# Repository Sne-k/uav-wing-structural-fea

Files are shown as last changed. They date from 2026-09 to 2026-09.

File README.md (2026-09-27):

# UAV Wing: Structural FEA (Fusion 360 + Ansys)

Design and finite-element analysis of a tapered UAV wing with skin, two spars and
ten ribs. This was a 6th-semester FEA project in B.Tech Aeronautical Engineering.

* **CAD:** Autodesk Fusion 360. The NACA 2412 airfoil is imported with a Python
  script, lofted, and given spars and ribs.
* **FEA:** Ansys Workbench 2026 R1 Student. Static structural, modal (6 modes),
  stress-life fatigue, and aluminium vs CFRP.
* **Audit and re-analysis:** the saved Ansys model was checked against its own
  solver files and against hand calculations. It was then re-solved with a small,
  benchmark-verified shell FE code with a corrected set-up. The analyses that
  were missing were also added: a derived design load, mesh convergence, skin
  sizing with buckling, a real composite layup with Tsai-Wu, fatigue and flutter.

<p align="center">
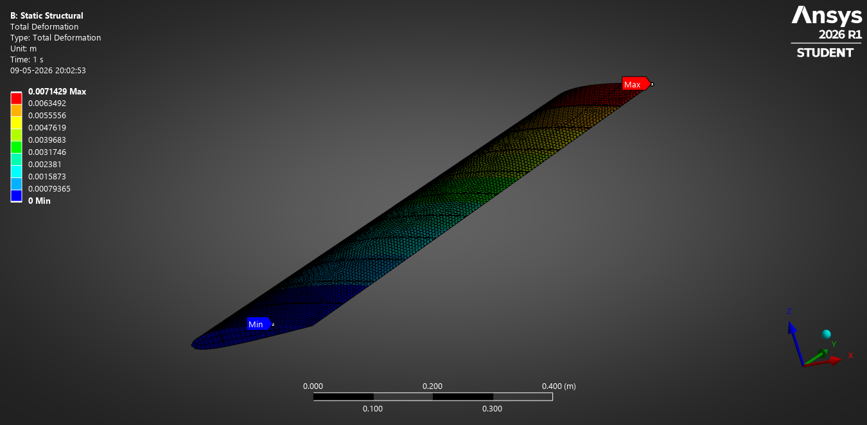
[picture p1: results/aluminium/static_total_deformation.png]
Ansys total deformation
  
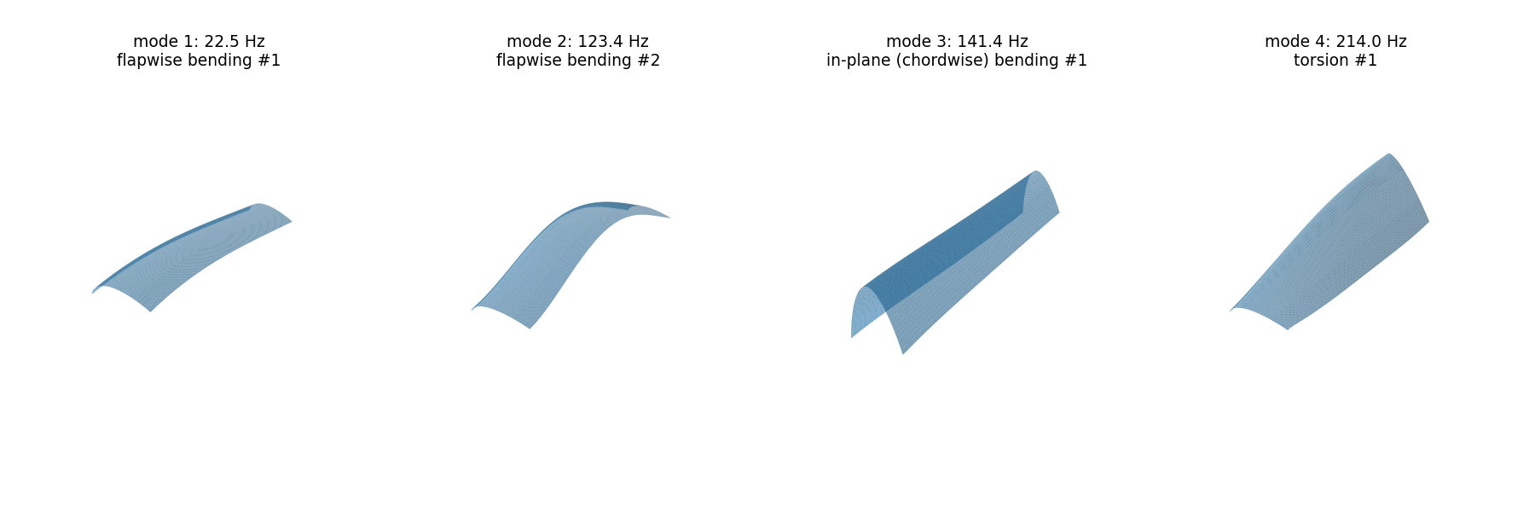
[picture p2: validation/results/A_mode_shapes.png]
Mode shapes of the corrected model
  
</p>

## The wing

| Item | Value |
|---|---|
| Airfoil | NACA 2412 |
| Semi-span | 1.2 m |
| Chord | 0.25 m at the root to 0.20 m at the tip (taper 0.8), straight leading edge, no sweep or twist |
| Front spar | straight, at 25 % of the root chord (x = 62.5 mm), 20 × 5 mm |
| Rear spar | tapered, on the 70 % chord line, 17 × 5 mm at the root |
| Ribs | 10, about 2 mm thick, 109 mm pitch |
| Materials | aluminium alloy (E 70 GPa, ρ 2700 kg/m³); "CFRP" (E 70 GPa, ρ 1600 kg/m³) |

## Workflow

```mermaid
flowchart LR
  A[Literature review<br/>5 papers] --> B[NACA 2412 .dat<br/>Fusion 360 script]
  B --> C[Loft, spars, ribs<br/>STEP export]
  C --> D[Ansys Workbench<br/>shell + solid mesh]
  D --> E[Static / modal /<br/>fatigue / CFRP]
  E --> F[Audit of solver decks<br/>and results]
  F --> G[Verified re-analysis<br/>validation/]
```

## Results of the original Ansys model

| Analysis | Aluminium | "CFRP" |
|---|---|---|
| Mass (semi-span) | 12.42 kg | 7.36 kg |
| Max total deformation | 7.14 mm | 7.14 mm |
| Max von Mises stress | 154.9 MPa | 157.9 MPa |
| Natural frequencies, modes 1–6 | 13.9, 23.9, 37.0, 63.9, 68.1, 87.7 Hz | 18.1, 31.0, 47.8, 83.0, 88.2, 113.9 Hz |
| Fatigue (zero-based, Goodman) | min. life 3.33 × 10⁶ cycles | – |

Screenshots are in [`results/`](results); the model is in [`ansys/`](ansys).

## Verification: what the numbers really say

The same wing solved four ways, all with the same 800 Pa load:

| | Your Ansys deck, as saved | Your Ansys deck, root clamped | Shell FE re-analysis, clamped (mesh-converged) | Beam theory, clamped |
|---|---|---|---|---|
| Tip deflection | 7.14 mm | **2.70 mm** | **2.70 mm** | 2.86 mm |
| Skin stress at the root | peak 154.9 MPa (at the spar root) | **10.6 MPa** | **10.7 MPa** | 10.2 MPa |
| 1st bending frequency | 13.9 Hz | **22.8 Hz** | **22.5 Hz** | 22.5 Hz |
| 1st in-plane bending | 23.9 Hz | **141 Hz** | **141 Hz** | – |
| 1st torsion | not found | **221 Hz** | **214 Hz** | – |

Re-solving the saved deck in Ansys MAPDL reproduces 7.14 mm and 154.9 MPa
exactly. Clamping the root **in that same deck** gives 2.70 mm, the same as
the independent shell model
([validation/ansys_rerun](validation/ansys_rerun/README.md)).
The audit
([docs/model_audit.md](docs/model_audit.md)) traces the difference to the set-up,
not to the software:

1. **Support.** The Fixed Support is on a separate root-cap surface that touches
   only the two spar end faces (8 and 13 contact nodes); the skin's root edge is
   free. The 154.9 MPa peak sits on that contact patch at the rear-spar root
   (22 MPa just 5 cm away). The soft joint also explains the extra deflection and
   the low frequencies.
2. **Load.** The 800 Pa was applied "by components" to the whole skin, so the
   lower surface is pushed up too: 434.6 N per semi-span, twice the intended
   load and about 17 g for a 5 kg UAV.
3. **"CFRP".** Modelled as isotropic with the same modulus as aluminium, so only
   the density changes. Deflection and stress are identical, and every frequency
   rises by exactly √(2700/1600) = 1.299.
4. **Mode 2** is in-plane (fore-aft) bending. **Modes 3–5** are local
   vibrations: modes 3 and 5 at the wing tip, and mode 4 on the front spar
   between ribs 2 and 3 (the spars are joined to the skin only by contact). No
   torsion mode is found. The fatigue life is computed at the same contact
   hotspot.

## Re-analysis and the gaps it fills ([validation/](validation/README.md))

* **Verified solver.** The shell element matches closed-form and published
  results within 1 % for plate bending, vibration, in-plane bending, plate
  buckling and the Scordelis-Lo roof. Closed-box torsion is within 3.3 %, as
  expected, because the clamped end restrains warping.
* **Confirmed in Ansys.** Your own decks, re-solved in Ansys MAPDL, reproduce
  the saved results exactly. With the root clamped they give 2.70 mm,
  22.8 Hz and 221 Hz torsion. With the design load, they give 0.82 mm and
  3.5 MPa in the skin
  ([validation/ansys_rerun](validation/ansys_rerun/README.md)). A corrected
  copy of the Workbench project, solved the same way, gives new screenshots
  ([results/corrected](results/corrected/README.md)).
* **Design load case.** 5 kg MTOW, limit load factor 4, safety factor 1.5.
  Spanwise lift comes from lifting-line theory and is applied to the upper skin
  with the centre of pressure at 25 % chord.
* **Sizing with buckling.** Under the design load the original 8 mm skin has a
  reserve factor of about 90 on ultimate strength. A **0.5 mm aluminium skin**
  passes strength (reserve factor 10 on yield at limit load, 7.7 on ultimate
  strength) and skin buckling (1.4 × ultimate) at **1.08 kg per semi-span
  instead of 12.8 kg**.
  A 0.4 mm skin buckles below ultimate load, so **buckling, not strength, sizes
  the skin**.
* **Real composite.** T300/5208 laminates with ply-level Tsai-Wu. A 0.75 mm
  [45/-45/0]s skin is **31 % lighter** than the sized aluminium wing, deflects
  34 % less, and has a 50 % higher first frequency (Tsai-Wu strength ratio 12.5,
  buckling 2.0 × ultimate).
* **Fatigue.** Stress amplitudes of 3–14 MPa give a life above 10⁷ cycles
  for 0 → 4 g manoeuvres and ±1 g gusts.
* **Flutter / divergence.** A Theodorsen typical-section estimate puts both
  above 300 m/s for the sized wing, about 8 times an assumed 40 m/s dive
  speed. The torsion/bending frequency ratio is about 9.6.

Full tables and plots are in [validation/README.md](validation/README.md).

## Repository layout

```
cad/          Fusion 360 and STEP geometry (final and archived versions), NACA 2412 coordinates
ansys/        final Ansys Workbench project (wing_fea.wbpj + wing_fea_files/)
results/      screenshots from the original Ansys runs (aluminium, cfrp)
docs/         model audit, literature review, development log, roadmap
tools/        solver-deck inspector, beam-theory check, Fusion 360 airfoil import script
validation/   verified shell FE code (wingfe/), benchmarks, re-analysis scripts and results
```

## Reproduce

```bash
pip install -r validation/requirements.txt
python validation/benchmarks.py         # verify the element (~10 s)
python validation/run_validation.py     # re-analysis, parts A-E (~0.5-1.5 h)
python validation/run_flutter.py        # flutter / divergence estimate
python validation/ansys_rerun/rerun_in_mapdl.py   # re-solve the saved decks in Ansys MAPDL (needs Ansys 2026 R1)
python tools/beam_check.py              # hand calculation
python tools/inspect_ds_dat.py ansys/wing_fea_files/dp0/SYS-2/MECH/ds.dat
```

To open the original model: Ansys Workbench 2026 R1 (Student is enough) →
`ansys/wing_fea.wbpj`. See [ansys/README.md](ansys/README.md).

## Documentation

* [docs/model_audit.md](docs/model_audit.md): verification and known issues, with evidence
* [docs/literature_review.md](docs/literature_review.md): the five reference papers, research gaps, objectives
* [docs/development_log.md](docs/development_log.md): how the project evolved, March to May 2026
* [docs/roadmap.md](docs/roadmap.md): what is still open

The reference papers are cited with links, not redistributed.

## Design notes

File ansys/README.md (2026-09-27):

# Ansys Workbench project

`wing_fea.wbpj` + `wing_fea_files/` is the final project, saved with **Ansys
2026 R1 Student**. Open the `.wbpj` in Workbench; keep the `.wbpj` and the
`_files` folder together and with the same base name.

| System | Content | Solver files |
|---|---|---|
| A | Original static system. It holds the shared Engineering Data; not solved | `dp0/global/MECH/SYS.mechdb` |
| B | Static Structural, aluminium, plus the Fatigue Tool | `dp0/SYS-2/MECH/` |
| C | Modal, aluminium (6 modes) | `dp0/SYS-3/MECH/` |
| D | Static Structural, "CFRP" (copy of B) | `dp0/SYS-4/MECH/` |
| E | Modal, "CFRP" | `dp0/SYS-5/MECH/` |

Each `MECH` folder keeps what the solver saw and produced:

* `ds.dat`: the complete MAPDL input deck (mesh, materials, contacts, loads)
* `solve.out`: solver log, including mass, frequencies and participation factors
* `file.rst`: results

The project was saved as `complete.wbpj` and renamed here together with its
`_files` folder. The renamed project opens in Workbench 2026 R1 Student
(checked in batch mode on a copy; the systems listed were "dummy", "static and
fatigue aluminium", "Modal aluminum", "CFRP static" and "CFRP modal"). The project file
also still contains stale absolute paths into the original project folder: the
geometry file `FEA Proeject (~recovered).step`, and a results file of the earlier
"unfailed attempt" project. The geometry is cached inside the project
(`dp0/SYS/DM/SYS.scdocx`). To update the geometry, re-point the geometry cell to
[`../cad/wing_final.step`](../cad/wing_final.step).

## Corrected project (`ansys/corrected/`)

`python validation/ansys_rerun/build_corrected_workbench.py` builds
`ansys/corrected/wing_fea_corrected.wbpj`, a copy of this project with the audit's
corrections, and re-solves all four systems. Result images are in
[`../results/corrected/`](../results/corrected/README.md).

The copy is about 110 MB; the script rebuilds it from scratch. If a system shows "Solve Required", re-solve just that system with
`--resolve al_static` (or `al_modal`, `cfrp_static`, `cfrp_modal`).

### Doing the same by hand in Workbench

1. Open `wing_fea.wbpj`, and double-click **Model** of a system to open Mechanical.
2. Right-click **Pressure** → **Suppress**.
3. Right-click the analysis (e.g. *Static Structural*) → **Insert → Commands**, and
   paste `validation/ansys_rerun/snippets/root_clamp.inp`. In static analyses, add a
   second **Commands** object with `design_load.inp`.
4. **Analysis Settings**: *Weak Springs* → **Off**. In modal analyses, set
   *Max Modes to Find* to **12** and add Total Deformation results for the extra
   modes.
5. **Solve**. Expected for aluminium:
   * design load: 0.81 mm and about 5.4 MPa;
   * modal: 22.8 Hz first bending and 221 Hz first torsion.

If MAPDL stops with "The memory (-m) size requested … is not currently
available", close other programs, or reduce the cores under **Home → Solve
Process Settings**. That is what happened on the first automated run.

The two Commands objects select nodes and elements by position, so they work on
any mesh of this geometry. The cleaner purely-GUI alternative:
* a **Fixed Support** scoped to the skin root edges and both spar root faces (or
  *Share Topology* in SpaceClaim, so the root cap is part of the skin);
* a **Pressure** on the upper skin, split into spanwise bands.

## Set-up as saved

| Item | Setting |
|---|---|
| Materials | "Aluminium aAlloy": E 70 GPa, ν 0.33, ρ 2700, UTS 310 MPa, S-N curve (10³…10⁷ cycles, 300…90 MPa). "cpfr": E 70 GPa, ν 0.3, ρ 1600, yield 500, UTS 600 MPa |
| Skin / caps | SHELL181, 8 mm / 0.1 mm, mid-surface offset |
| Ribs, spars | SOLID186 |
| Connections | 16 bonded contacts |
| Support | Fixed Support on the root cap (Body44) only |
| Load | Pressure by components, Z = 800 Pa, on all skin faces (resultant 434.6 N) |
| Analysis | linear, weak springs on; modal: 6 modes |
| Fatigue | stress-life, zero-based, Goodman, von Mises, Kf = 1 |

**Read [../docs/model_audit.md](../docs/model_audit.md) before using these
results**: the support and load definitions drive the reported peak stress,
deflection and frequencies.

## Inspecting the decks without Ansys

```bash
python tools/inspect_ds_dat.py ansys/wing_fea_files/dp0/SYS-2/MECH/ds.dat
python validation/read_ansys_results.py        # needs: pip install ansys-mapdl-reader
python validation/ansys_rerun/rerun_in_mapdl.py # re-solve in MAPDL, as saved and corrected (needs Ansys)
```

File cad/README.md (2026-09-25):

# CAD (Autodesk Fusion 360)

| File | What it is |
|---|---|
| `wing_final.f3d` / `wing_final.step` | Geometry used by the final Ansys project. Skin as a surface body (`Wing_body`), root and tip closing faces (`Body44`, `Body45`), 10 solid ribs, 2 solid spars. |
| `naca2412.dat` | NACA 2412 coordinates in Selig format (generated from the NACA 4-digit equations) for [`tools/fusion_import_airfoil.py`](../tools/fusion_import_airfoil.py). |
| `archive/v1_solid_wing_2026-04-19.step` | First all-solid model (wing, spars, ribs), used in the failed April solve. |
| `archive/v2_skin_ribs_spar_2026-04-30.step` | Intermediate: skin surface, ribs, one spar. |
| `archive/v5_variant_unused_2026-05-09.*` | A variant with extra surface bodies and no spars. It was tried, then reverted. |

## Geometry

Values below were measured from the Ansys mesh, so they are what was actually
analysed.

| Item | Value |
|---|---|
| Airfoil | NACA 2412 (12 % thick at 30 % chord, 2 % camber at 40 % chord), finite TE 0.26 % c |
| Semi-span | 1.200 m |
| Root / tip chord | 0.250 m / 0.200 m (taper 0.8), leading edge straight at x = 0 |
| Sweep, twist, dihedral | 0 |
| Front spar | straight, x = 62.5–67.5 mm, 20 mm deep (25 % of root chord, 31 % at the tip) |
| Rear spar | on the 70 % chord line (tapered), 5 mm wide, 17 mm deep at the root |
| Ribs | 10, about 2 mm thick, at y = k × 1.2/11 (109 mm pitch) |

Axes: x chordwise (aft), y spanwise (root → tip), z up.

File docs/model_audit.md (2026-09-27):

# Model audit: verification and known issues

This page checks the saved Ansys model against:

* what the solver actually received (`ds.dat`) and produced (`solve.out`, `file.rst`);
* hand calculations;
* an independent, benchmark-verified shell FE model of the same wing with a
  correctly clamped root ([`validation/`](../validation/README.md)).

Every number can be reproduced:

```bash
python tools/inspect_ds_dat.py ansys/wing_fea_files/dp0/SYS-2/MECH/ds.dat   # what the solver received
python validation/read_ansys_results.py                                      # Ansys results (pip install ansys-mapdl-reader)
python tools/beam_check.py                                                   # beam theory
python validation/run_validation.py                                          # independent re-analysis
```

## 1. What the solver received

| Item | Value in the solver deck |
|---|---|
| Skin (`Wing_body`) | SHELL181, **8 mm**, mid-surface on the outer mould line, 12 870 elements, all triangles |
| Root cap (`Body44`) and tip cap (`Body45`) | SHELL181, 0.1 mm, 62 and 37 elements |
| Ribs 1 to 10 | SOLID186, about 2 mm thick, 41 to 59 elements each, at y = 0.109 to 1.091 m |
| Spars | SOLID186; spar 1 straight at x = 62–67 mm (25 % of root chord); spar 2 tapered, on the 70 % chord line |
| Connections | 16 bonded contacts (listed in 3.1); no shared topology, so every body is meshed separately |
| Fixed Support | **87 nodes, all on `Body44` (the root cap)** |
| Load | 800 Pa by components along +Z on **every skin facet (upper and lower surfaces)**; total reaction **434.6 N** |
| Solver options | linear static, weak springs on; modal: 6 modes |
| Mass | 12.419 kg (aluminium), 7.359 kg ("CFRP"); the 8 mm skin alone is about 11.95 kg |

## 2. Cross-check: four answers

| Quantity | Ansys, deck as saved | Ansys, same deck with the root clamped | Shell FE re-analysis, clamped (converged) | Beam theory, clamped |
|---|---|---|---|---|
| Tip deflection | **7.14 mm** | **2.70 mm** | **2.70 mm** | 2.86 mm |
| Peak von Mises | **154.9 MPa** (rear-spar root) | skin **10.6 MPa** at the root; 17.7 MPa local peak inside rib 2 | 10.7 MPa (web/skin root corner) | 10.2 MPa (root bending) |
| 1st flapwise bending | 13.89 Hz | 22.77 Hz | 22.50 Hz | 22.5 Hz (Rayleigh) |
| 1st in-plane bending | 23.86 Hz | 141.3 Hz | 141.4 Hz | – |
| 1st torsion | not in the first 6 modes | 221.4 Hz | 214.0 Hz | – |
| Load / reaction | 434.6 N | 434.5 N | 440.9 N | 441 N |
| Mass | 12.42 kg | 12.42 kg | 12.85 kg (full-depth webs) | 11.95 kg (skin only) |

The second column is the student's own Ansys deck re-solved in Ansys MAPDL with
one change: every node in the root plane is clamped
([validation/ansys_rerun](../validation/ansys_rerun/README.md)). Re-solving the
deck unchanged reproduces 7.143 mm and 154.91 MPa exactly.

With the root clamped, Ansys and the independent shell model agree:
* tip deflection to within 0.0 %;
* skin root stress to within 1 %;
* first bending frequency to within 1 %;
* torsion frequency to within 3.4 %.

**The support definition alone explains the difference.** The next section
explains why.

## 3. Known issues, ordered by impact

### 3.1 The wing is supported only through the spar end faces (critical)

The contact map from `ds.dat`:

| Contact regions | Joins |
|---|---|
| 1–10 | skin to rib 1 … rib 10 |
| 11, 12 | skin to spar 1, skin to spar 2 |
| 13, 14 | **root cap (`Body44`) to spar 1 (13 nodes), and to spar 2 (8 nodes)** |
| 15, 16 | tip cap (`Body45`) to spar 1, and to spar 2 |

The Fixed Support is on the root cap, and **no contact joins the skin to the
root cap**. The skin's root edge is therefore free. The entire root bending
moment (about 255 N·m) goes from the skin into the spars, and then through two
small contact patches (8 and 13 nodes) on the spar end faces into the support.

The result file confirms it (`validation/results/ansys_rst_readback.txt`). The
maximum von Mises, **154.9 MPa, is at the root end of spar 2** (y = 0), on the
8-node contact patch. Along that spar it falls to 91 MPa within 20 mm, 22 MPa at
50–100 mm, and 6 MPa beyond 200 mm. It is a local artefact of the connection,
not a wing stress.

Consequences:

* The reported "maximum stress near the root" and the factor of safety (1.61)
  describe the connection patch.
* The whole wing rotates about that soft root joint, which gives the 7.14 mm tip
  deflection instead of about 2.7 mm. It also gives the low 13.9 Hz bending and
  23.9 Hz in-plane frequencies instead of 22.5 Hz and 141 Hz.
* The fatigue minimum life (3.33 × 10⁶ cycles) sits on the same patch. It checks
  out exactly: zero-based loading, σa = σm = 77.5 MPa, Goodman with Su = 310 MPa
  gives 103 MPa, and on the S-N curve that is 3.3 × 10⁶ cycles. So the fatigue
  result describes the patch, not the wing.
* The "thickness optimisation" iterations were steered toward target
  deflection and stress ranges rather than design requirements. Their numbers
  can't be used for sizing.

**Fix:** clamp the complete root section (skin edge and both spar root faces),
or share topology between the root cap and skin. Then switch off weak springs
and confirm the solution still converges. The re-analysis does exactly this.

### 3.2 The load is doubled and not physically derived (high)

* The 800 Pa is defined **by components (+Z)** on the **whole** skin, so the
  lower surface is pushed upward too. The total is 434.6 N per semi-span, equal to
  1600 Pa over the 0.27 m² planform: twice the intended load.
* At the stated 20 m/s cruise (q = 245 Pa), that would need C_L ≈ 6.6. For the
  stated 5 kg UAV, one semi-span carries about 25 N in level flight, so the model
  applies about 17 g.
* XFLR5 (VLM2, α = 4–8°) was run, but the spanwise lift was never extracted. The
  800 Pa was a placeholder after the coordinate-based pressure expression failed.

**Fix:** a stated design case (mass, load factor, safety factor). Take the
spanwise lift from lifting-line theory, XFLR5 or a Schrenk distribution, and
apply it to the upper skin. The re-analysis uses a 5 kg MTOW, n_limit = 4 and a
1.5 safety factor, with lifting-line lift (Part B).

### 3.3 The "CFRP" case only changes the density (high)

Both materials use E = 70 GPa. Only ν (0.30 vs 0.33) and ρ (1600 vs 2700) differ.
So the static results are identical (7.137 vs 7.143 mm, 157.9 vs 154.9 MPa), and
every frequency rises by exactly √(2700/1600) = 1.299, a pure mass effect. The
re-analysis reproduces this: 1.298.

A carbon laminate has no yield point and fails ply by ply, so von Mises stress,
a 500 MPa "yield" and a factor of safety are not meaningful for it. These
results support **"same stiffness, 41 % lighter"**. They do **not** support
"stiffer", "less deformation" or "better flutter resistance".

**Fix:** orthotropic plies and a real layup, evaluated with Tsai-Wu or Hashin.
The re-analysis uses T300/5208 plies with classical lamination theory (Part D).

### 3.4 Modal results were mis-labelled (medium)

Participation factors from `solve.out` (aluminium; CFRP scales by 1.299):

| Mode | f [Hz] | Dominant effective mass | What it actually is |
|---|---|---|---|
| 1 | 13.89 | Z 67 %, ROTX 99 % | 1st **flapwise** bending |
| 2 | 23.86 | X 72 %, ROTZ 94 % | 1st **in-plane** bending (6 times too low, see 3.1) |
| 3 | 36.98 | ≈ 0 in all directions | local mode at the tip leading edge (normalised amplitude 149) |
| 4 | 63.93 | ≈ 0 | local vibration of the front spar between ribs 2 and 3 (peak at x = 0.065, y = 0.31 m). Still present with the root clamped (64.1 Hz), because the spars are joined only to the skin, by contact |
| 5 | 68.12 | ≈ 0 | local mode at the tip trailing edge (normalised amplitude 341) |
| 6 | 87.75 | Z 18 % | 2nd **flapwise** bending (87.75 / 13.89 = 6.3; textbook cantilever 6.27) |

No torsion mode appears in the first six, so the modal results say nothing about
bending–torsion coupling or flutter. With the root clamped, the first eight
modes are: 22.5 (flap 1), 123.4 (flap 2), 141.4 (in-plane 1), 214.0
(**torsion 1**), 317.5, 567.8, 574.9 and 700.7 Hz. The Ansys deck with the root clamped gives 22.8 (flap 1), 123.2
(flap 2), 141.3 (in-plane 1) and 221.4 Hz (torsion 1), plus local modes of the tip cap and front spar.

### 3.5 Sizing is far from a UAV wing (medium)

Under the design ultimate load (6 g on a 5 kg aircraft), the saved design reaches
only 3.4 MPa (reserve factor 92 on ultimate strength, 123 on yield at limit load)
and deflects 0.8 mm. A semi-span weighs
12.8 kg, so the two wings weigh about five times the whole aircraft. Part C of
the re-analysis sizes the skin with strength and buckling checks.

### 3.6 Mesh and model quality (medium)

* The skin mesh is 100 % degenerate triangular SHELL181. Ansys recommends
  triangles only as filler because they are overly stiff; use a quad-dominant
  mesh.
* There is no mesh-convergence study. (The re-analysis includes one: tip
  deflection changes 0.07 % between the last two meshes.)
* An 8 mm skin with mid-surface offset sits 4 mm outside the aerodynamic surface
  and overlaps the solid spars and ribs by 4 mm.
* Ribs are bonded only to the skin, not to the spars.
* Weak springs hide constraint problems. The April solid model failed with a
  pivot error at rib 5 for the same kind of reason.
* Aluminium has no yield strength defined in Engineering Data, so Mechanical
  cannot compute a safety factor. The FoS of 1.61 was computed by hand from the
  artefact stress.

### 3.7 Documentation consistency (low)

* The airfoil is **NACA 2412**. The root mesh nodes match it: 12.0 % thick at
  30 % chord, 2 % camber at 40 % chord. Some earlier write-ups say
  "NACA 63(1)-412".
* The elliptical-load expression tried in Mechanical assumed a 0.35 m semi-span
  instead of 1.2 m. The XFLR5 file isn't in the project folder, so it can't be
  checked that the aerodynamic and structural models match.
* The "5 kg UAV" mass is used but never justified.

## 4. What is solid

* The CAD and FE pipeline works end to end: airfoil import script, tapered loft,
  ribs, a tapered rear spar, STEP export, a shell-plus-solid idealisation, and
  linked static, modal and fatigue systems.
* Within the saved model, the numbers are internally consistent. The reaction
  equals the applied load; the CFRP frequency ratio is exactly 1.299; the fatigue
  life follows exactly from Goodman and the S-N curve; and mode 6 / mode 1 = 6.3,
  like a textbook cantilever.
* The fatigue method is sound: zero-based loading, Goodman and an S-N curve with
  a UTS entered. It just needs the correct stress field.

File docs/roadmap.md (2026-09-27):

# Roadmap: what is left to do

The re-analysis in [`validation/`](../validation/README.md) closes the main gaps
found in the [audit](model_audit.md). This list covers what is still open,
most valuable first.

## Needs Ansys (Workbench / Mechanical / ACP)

1. **Rebuild the Workbench model with the corrections**, so the submitted
   screenshots match the verified numbers. The corrected set-up has already
   been re-solved in Ansys MAPDL on the saved mesh
   ([validation/ansys_rerun](../validation/ansys_rerun/README.md)). A corrected
   Workbench project has also been built and solved by script
   (`validation/ansys_rerun/build_corrected_workbench.py`; images in
   `results/corrected/`). What is left is the cleaner GUI version:
   * Fixed Support on the skin root edge and both spar root faces, or use
     *Share Topology* in SpaceClaim so the root cap is part of the skin.
   * Pressure *Normal To* the **upper skin only**, not "Components Z" on the
     whole skin. Split the upper surface into 4–6 spanwise bands carrying the
     lifting-line load in `validation/results/B_spanwise_lift_ultimate.csv`, or
     apply the same forces with an APDL command snippet.
   * Quad-dominant mesh on the skin, shell offset *Bottom* (inward), weak
     springs off.
   * Target values to reproduce: `validation/results/summary.json` (Part A:
     2.70 mm, 22.5 Hz).
2. **Composite layup in Ansys ACP** (T300/5208, the Part D layups) with ply-wise
   Tsai-Wu or Hashin, checked against Part D.
3. **Eigenvalue buckling** in Workbench (Static → Eigenvalue Buckling), checked
   against Part C.

## Engineering scope

4. **V-n diagram and load cases**: manoeuvre (+n, −n), gust (Pratt formula at
   V_C and V_D), and landing/handling cases. At the moment only +4 g limit /
   +6 g ultimate is analysed.
5. **Root fitting and spar-cap design**: the root joint (lugs, bolts or a
   carry-through spar) is where real wings fail. Bearing and shear-out checks.
6. **Stringers or a sandwich skin** if thinner skins are wanted: buckling
   governs the lighter aluminium options.
7. **Aerodynamic-structural coupling**: map XFLR5 or CFD pressures onto the
   structure and iterate on the deformed shape (loosely coupled, as in Chen et
   al.). Not significant at these deflections, but good to demonstrate.
8. **Flutter**: the typical-section estimate (Part F) is a first check. A
   modal-based p-k analysis with a doublet-lattice or strip-theory model of the
   whole wing would confirm the margin.
9. **Fatigue spectrum**: replace the constant-amplitude cycles with a mission
   spectrum (ground-air-ground plus gust exceedances), use Miner's rule, and
   use S-N data for the actual alloy and joint detail.

## Validation

10. **Physical test**: a simple static test (sandbag or whiffletree loading
    of a built wing, with tip deflection measured by a dial gauge) against the
    predicted deflection and strain. That turns the numbers into validated
    results.

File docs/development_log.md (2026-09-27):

# Development log

How the project evolved, reconstructed from the working notes and the files in
this repository. Dates are 2026.

## March: literature and planning
* Literature review of five papers ([literature_review.md](literature_review.md)),
  research gaps and objectives, and a first presentation draft.
* Wing parameters chosen: **NACA 2412**, semi-span **1.2 m**, root chord
  **0.25 m**, tip chord **0.20 m** (taper 0.8), no sweep at the leading edge, no
  twist.
* Airfoil coordinates (Selig format) imported into Fusion 360 with a small Python
  script ([`tools/fusion_import_airfoil.py`](../tools/fusion_import_airfoil.py)).
  Fixes needed along the way: a UTF-8 byte-order mark in the `.dat` file, and
  `ObjectCollection` instead of a Python list for the spline points.
* Loft between root and tip sections, after closing the trailing edge so the
  profiles are closed regions.

## March–April: internal structure in Fusion 360
* Front spar at 25 % of the root chord (x = 62.5 mm), 20 × 5 mm. Rear spar at
  70 % chord, 17 × 5 mm.
* Spars extruded "To Object" along the span. "Join" failed until the spar
  profiles were fully inside the section.
* The rear spar stuck out of the thinner tip section, so it was **tapered** to
  follow the 70 % chord line.
* Ten ribs at 109 mm pitch (span / 11). Rib profiles were made with Intersect
  because the wing tapers. They were first joined into one solid, then kept as
  separate bodies.

## 19–20 April: first Ansys attempt (solid model), "failed attempt"
* The all-solid STEP (`cad/archive/v1_solid_wing_2026-04-19.step`) imported into
  Workbench: 41k nodes, 35 contact regions (105k contact elements), 80 Pa.
* The solver stopped with **"small pivot"** errors at rib 5 (UX): parts were not
  properly connected, and thin solids had one element through the thickness.
* A merged single-solid variant solved: 0.55 mm and 1.49 MPa at 100 Pa. The
  decision was then to rebuild as a **shell model**.

## 30 April – 9 May: shell model
* The skin was converted to a surface in Fusion (`new geo.step`, then
  `wing_final.step`). The root and tip closing faces became separate surface
  bodies (Body44, Body45).
* Meshed with SHELL181 (skin and caps) and SOLID186 (ribs and spars), plus 16
  bonded contacts. Mesh warnings were accepted.
* XFLR5: wing built, VLM2 analysis at 20 m/s for α = 4–8°. The spanwise load
  could not be exported from the UI version in use. Coordinate-based pressure
  functions in Mechanical also failed ("Y is undefined"), so a uniform
  **800 Pa** was used instead.
* Pivot error on Body45 (the tip cap had a free ROTX DOF). The saved model bonds
  the tip cap to both spars (contact regions 15–16), which is the likely fix.
  Weak springs were switched on later, during the thickness iterations.
* Iterations on shell thickness gave tip deflections of 0.012 → 0.055 → 0.21 mm,
  then an unstable run, then a 11.4 m "rigid-body" result, and finally the saved
  configuration: **8 mm skin, 0.1 mm end caps → 7.14 mm, 154.9 MPa**.
* Modal analysis (6 modes): 13.9 to 87.7 Hz.

## 10 May: CFRP and fatigue
* The static and modal systems were duplicated with "CFRP": E = 70 GPa,
  ν = 0.3, ρ = 1600 kg/m³ (from paper 4). Results: 7.137 mm, 157.9 MPa,
  frequencies × 1.30, mass −41 %.
* Fatigue on the aluminium static system: S-N curve (300 MPa at 10³ cycles down
  to 90 MPa at 10⁷), UTS 310 MPa, zero-based loading, Goodman. Minimum life
  **3.33 × 10⁶ cycles**.
* Conclusions and a flutter discussion were written, and the project was added
  to the CV.

## September: repository, audit and re-analysis
* Everything organised into this repository.
* The solver decks and result files were audited
  ([model_audit.md](model_audit.md)). The root boundary condition and the load
  definition turned out to drive the reported stress, deflection and
  frequencies.
* Independent re-analysis with a verified shell FE code, a clamped root, a
  derived design load, sizing with buckling, a composite laminate study and
  fatigue ([validation/README.md](../validation/README.md)).

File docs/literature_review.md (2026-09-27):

# Literature review

These five sources shaped the project. The PDFs are **not** redistributed in
this repository because they are copyrighted; follow the links or DOIs instead.

| # | Reference | Access |
|---|---|---|
| 1 | Tang J., Xi P., Zhang B., Hu B., *A finite element parametric modeling technique of aircraft wing structures*, Chinese Journal of Aeronautics 26(5), 1202–1210, 2013 | [doi:10.1016/j.cja.2013.07.019](https://doi.org/10.1016/j.cja.2013.07.019) (open access) |
| 2 | Chen H. H., Chang K. C., Tzong T., Cebeci T., *Aeroelastic Analysis of Aircraft: Wing and Wing/Fuselage Configurations*, McDonnell Douglas report MDC 97K0164 for NASA Ames (contract NAS2-14091), 1997 | [NTRS 19980003841](https://ntrs.nasa.gov/citations/19980003841) |
| 3 | Noor Abdi A., Kapesa T. G., *Optimization of Composite Structures of an Aircraft Wing*, Int. J. of Modern Research in Engineering and Technology 8(7), 2023 | ijmret.org, ISSN 2456-5628 |
| 4 | Peruru S. P., Abbisetti S. B., *Design and Finite Element Analysis of Aircraft Wing Using Ribs and Spars*, IRJET 4(6), 2133–2139, 2017 | irjet.net, e-ISSN 2395-0056 |
| 5 | Vinay Kumar P., Rahul Raj I., Snehith Reddy M., Siva Prasad N., *Design and Finite Element Analysis of Aircraft Wing using Ribs and Spars*, Turkish J. of Computer and Mathematics Education 12(8), 3224–3230, 2021 | turcomat.org |

## What each source contributes

**1. Parametric FE modelling (Tang et al., 2013).** Building an FE model of a
wing by hand (geometry, mid-surfaces, mesh, properties) is slow and error-prone.
The authors encode design rules and expert knowledge in templates. A *skeleton
model* (the layout of spars, ribs and stringers) drives a *geometric mesh model*,
which drives the *FE model*, so the whole model regenerates when a parameter
changes. It targets preliminary design, where many layouts must be analysed
quickly.
*Relevance:* the project's CAD/FE hand-off was the most time-consuming part.
Parametrising the layout (rib pitch, spar positions, thicknesses) is exactly how
[`validation/wingfe/wing.py`](../validation/wingfe/wing.py) rebuilds the model.

**2. Aeroelastic analysis with a loosely coupled interface (Chen et al., 1997).**
Aerodynamic pressures from a flow solver are converted into structural nodal
forces by virtual work. The FE deflections are then mapped back onto the
aerodynamic surface, and the loop repeats until loads and shape converge. For a
transport wing at cruise, the elastic deformation noticeably changes the pressure
distribution and shock position compared with a rigid wing, and the coupled
results agree better with wind-tunnel data.
*Relevance:* it motivates deriving the structural load from an aerodynamic
analysis rather than assuming a pressure. It also shows that modal and aeroelastic
checks, not just static stress, belong in wing design.

**3. Composite wing optimisation (Noor Abdi & Kapesa, 2023).** A broad overview
of optimising composite wing structures together with aerodynamic shape
(twist and thickness distributions, pressure distributions) for weight and
performance. It gives limited quantitative detail about the structural model.
*Relevance:* background for the aluminium-versus-composite comparison and for
treating weight as an objective.

**4. Wing with ribs and spars in Pro/E and Ansys (Peruru & Abbisetti, 2017).** A
trainer-aircraft wing with skin, 15 ribs, an I-section front spar and a
C-section rear spar, analysed in Ansys 14.5 (static, fatigue, modal). It compares
Al 6061-T8, S2-glass and carbon/epoxy at several speeds.
*Relevance:* this is the template for the project workflow (CAD → Workbench →
static/fatigue/modal → material comparison). The project's CFRP properties
(E = 70 GPa, ν = 0.3, ρ = 1.6 g/cc, isotropic) come from this paper's material
table. Treating carbon/epoxy as isotropic with the same modulus as aluminium is
the simplification that made the project's CFRP comparison a pure density change.

**5. Wing with ribs, spars and winglets (Vinay Kumar et al., 2021).** A CATIA
wing (15 ribs, I- and C-section spars) with winglets at 25° and 45°. It is
analysed in Ansys for S2-glass, Kevlar-49 and boron fibre. Boron fibre gave the
lowest deformation and stress of the three materials. The winglet angle made
little difference: in the paper's own table, 25° gives the lowest deformation
(0.000444 vs 0.000466) and 45° a marginally lower stress (12.236 vs 12.254,
0.15 % lower).
*Relevance:* same workflow as paper 4. It also shows how a configuration change
(winglets) can be studied within the same FE framework.

## Research gaps the project set out to address

1. Studies tend to treat aerodynamics and structure separately. Few derive the
   structural load from an aerodynamic analysis of the same wing (papers 2, 4, 5).
2. Many student-level studies stop at static stress; modal and fatigue checks are
   often missing (papers 4, 5).
3. Composite comparisons usually use isotropic "equivalent" properties rather
   than laminate (ply-level) modelling (papers 4, 5).
4. Building the FE model by hand is slow and hard to iterate (paper 1).

## Objectives (as stated for the project)

1. Design a 3D wing with skin, spars and ribs in CAD.
2. Build an FE model in Ansys Workbench.
3. Run static structural analysis for stress and deformation.
4. Run modal analysis for natural frequencies and mode shapes.
5. Run fatigue analysis to estimate life.
6. Compare aluminium with CFRP and evaluate strength-to-weight.

How far the original analysis met these objectives, and how the re-analysis in
[`validation/`](../validation/README.md) closes the remaining gaps, is covered in
[model_audit.md](model_audit.md).

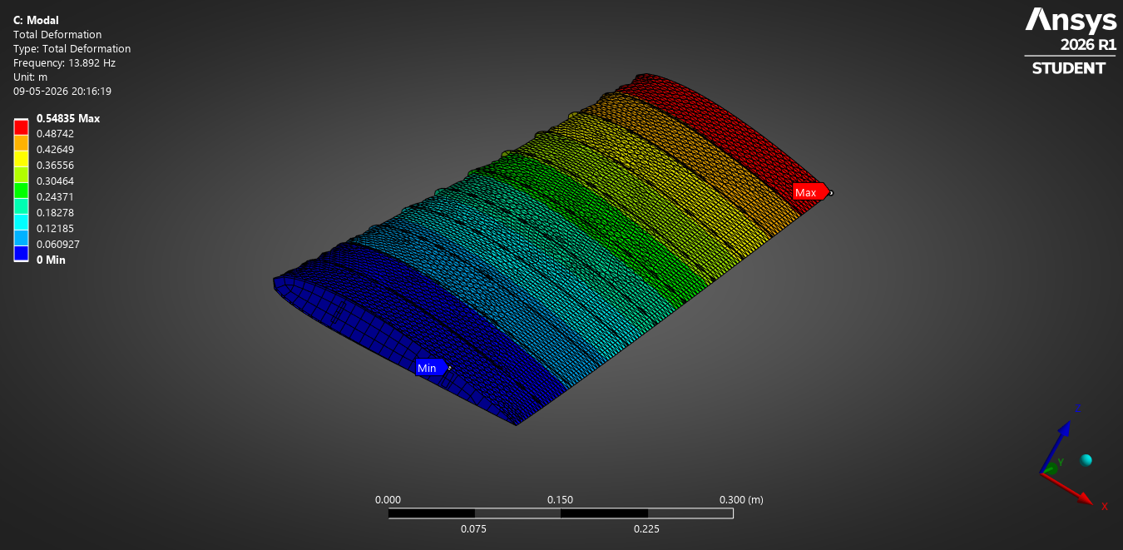
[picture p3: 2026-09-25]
ansys/corrected/wing_fea_corrected_files/dp0/global/MECH/SYS-5/Figures and Images/StaticFigure124.png

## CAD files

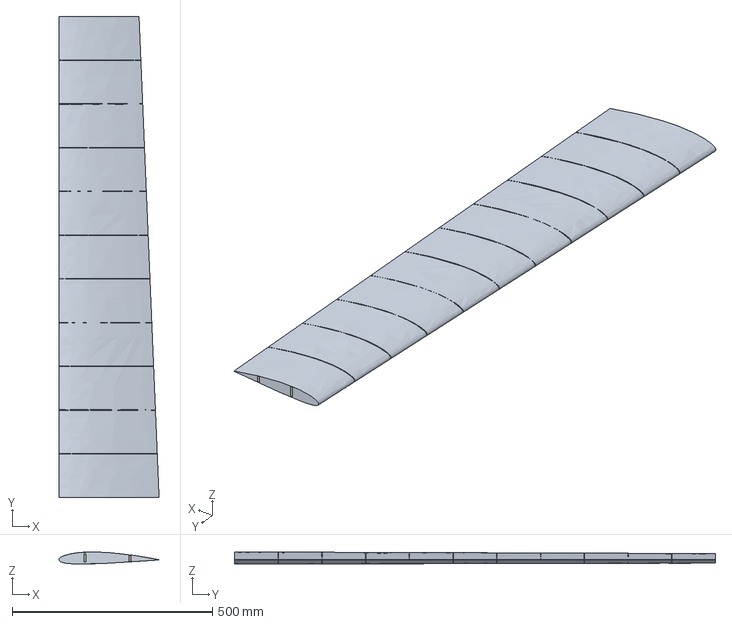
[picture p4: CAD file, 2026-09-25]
cad/wing_final.step
250.0 x 1200.0 x 30.3 mm

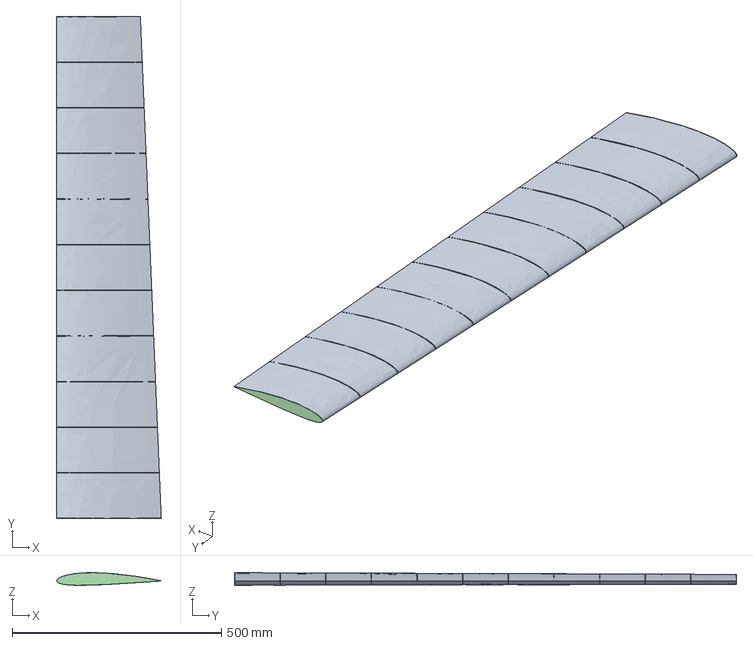
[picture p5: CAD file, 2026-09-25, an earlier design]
cad/archive/v2_skin_ribs_spar_2026-04-30.step
250.0 x 1200.0 x 30.3 mm

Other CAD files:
cad/archive/v1_solid_wing_2026-04-19.step
cad/archive/v5_variant_unused_2026-05-09.step
cad/archive/v5_variant_unused_2026-05-09.f3d
cad/wing_final.f3d

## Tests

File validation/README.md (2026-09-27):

# Independent re-analysis ("validation")

The Ansys model saved in [`../ansys`](../ansys) has a support and load set-up
that drives its headline numbers (see [../docs/model_audit.md](../docs/model_audit.md)).
Ansys is not needed to re-solve the problem correctly, so this folder does it
with a small, verified shell FE code written for the purpose. It then covers
the analyses the project promised but did not complete.

```bash
pip install -r validation/requirements.txt
python validation/benchmarks.py        # element verification            (~10 s)
python validation/run_validation.py    # parts A-E                       (~0.5-1.5 h)
python validation/run_flutter.py       # part F, after run_validation    (~2 min)
python validation/read_ansys_results.py  # read the original Ansys .rst files
```

All outputs land in [`results/`](results).

## The code (`wingfe/`)

| Module | Content |
|---|---|
| `shell.py` | 4-node flat shell, 6 DOF per node: Q4 membrane with incompatible modes (QM6), MITC4 Reissner-Mindlin bending/shear, drilling penalty tied to the in-plane rotation, consistent mass, geometric stiffness for buckling. Takes A-B-D laminate matrices directly. |
| `materials.py` | Isotropic sections; classical lamination theory (Q̄, A, B, D, transverse shear); Tsai-Wu. T300/5208 ply data from Kaw, *Mechanics of Composite Materials*. |
| `model.py` | Sparse assembly; static (`spsolve`), modal (shift-invert Lanczos), linear buckling; effective-mass participation. |
| `wing.py` | Parametric mesh of the project wing (NACA 2412, 1.2 m semi-span, taper 0.8, spars at 25 % root chord and 70 % chord, 10 ribs plus a tip rib). Skin, webs and ribs share nodes (no contacts). Loads and stress recovery. |
| `aero.py` | Prandtl lifting-line (Glauert) and Schrenk spanwise lift. |
| `flutter.py` | Typical-section bending–torsion flutter with Theodorsen aerodynamics (V-g method) and divergence. |

### Verification ([`results/benchmarks.csv`](results/benchmarks.csv))

| Benchmark | wingfe | Reference | Error |
|---|---|---|---|
| Cantilever plate, tip deflection | 0.057111 m | 0.057146 m (Timoshenko beam) | −0.06 % |
| Cantilever plate, 1st frequency | 8.2272 Hz | 8.2252 Hz | +0.02 % |
| Deep web in in-plane bending, 10 × 1 mesh (locking test) | 5.737 mm | 5.759 mm | −0.39 % |
| Simply supported plate buckling, k = 4 | 2.539 × 10⁵ N/m | 2.531 × 10⁵ N/m | +0.33 % |
| Closed box torsion, clamped end | 6.89 × 10⁻⁴ rad | 7.13 × 10⁻⁴ rad (Bredt-Batho, free warping) | −3.3 % (end restraint) |
| Scordelis-Lo roof, 20 × 20 (curved-shell benchmark) | 0.3022 | 0.3024 | −0.05 % |
| [0]₈ / [90]₈ laminate strip, tip deflection | – | CLT D-matrix | −0.13 % / −0.09 % |
| Lifting line, elliptic wing: C_Lα / span efficiency | 5.3999 /rad / 1.000 | 5.3997 /rad / 1 (closed form) | 0.00 % |
| Theodorsen function C(k) at k = 0.1, 0.5, 1.0 (Hankel form) | e.g. 0.8319 − 0.1723i | independent modified-Bessel form K₁/(K₀+K₁) | 0.00 % |
| Typical-section flutter: speed rises as the CG moves forward | yes (U_F/(bω_α) = 2.18 at x_α = 0.1) | expected physical trend | – |
| Rigid-body motion of the assembled wing | ‖K·r‖ / max K_ii = 9.6 × 10⁻⁷ | 0 | – |

Every row is produced by `benchmarks.py`. The flutter code has no published
reference case here; it is checked through Theodorsen's function and the
mass-balance trend.

## Results

### Part A: original geometry and load, root clamped ([A_mesh_convergence.csv](results/A_mesh_convergence.csv))

Same geometry, thicknesses and 800 Pa as the Ansys model. The only change: the
root section (skin edge and both spar webs) is clamped, and all parts share
nodes.

| Mesh | DOF | Tip deflection | Max von Mises | Von Mises beyond y = 0.05 m | f1 flap | In-plane | Torsion |
|---|---|---|---|---|---|---|---|
| × 0.5 | 3 498 | 2.746 mm | 9.43 MPa | 7.95 MPa | 22.31 Hz | 141.2 Hz | 212.6 Hz |
| × 1.0 | 16 524 | 2.707 mm | 9.98 MPa | 8.16 MPa | 22.47 Hz | 141.3 Hz | 213.8 Hz |
| × 1.5 | 39 318 | 2.700 mm | 10.38 MPa | 8.34 MPa | 22.49 Hz | 141.4 Hz | 213.9 Hz |
| × 2.0 | 70 350 | **2.698 mm** | 10.67 MPa | **8.33 MPa** | **22.50 Hz** | **141.4 Hz** | **214.0 Hz** |

Deflection, frequencies and stress away from the root converge. The peak value
creeps up slowly at the re-entrant corner where the webs meet the clamped skin,
a mild local effect. For comparison, beam theory gives 2.86 mm, 10.2 MPa and
22.5 Hz; Ansys gave 7.14 mm, 154.9 MPa and 13.9 Hz.

With the project's isotropic "CFRP" (E 70 GPa, ρ 1600 kg/m³), the static result
is identical (2.704 mm) and f1 = 29.20 Hz, exactly 1.298 × the aluminium value.

Modes of the corrected model ([A_modes_aluminium.csv](results/A_modes_aluminium.csv)):
22.5 Hz flap 1, 123.4 Hz flap 2, 141.4 Hz in-plane 1, **214.0 Hz torsion 1**,
317.5 Hz flap 3, 567.8 Hz torsion 2, 574.9 Hz flap 4, 700.7 Hz in-plane 2.

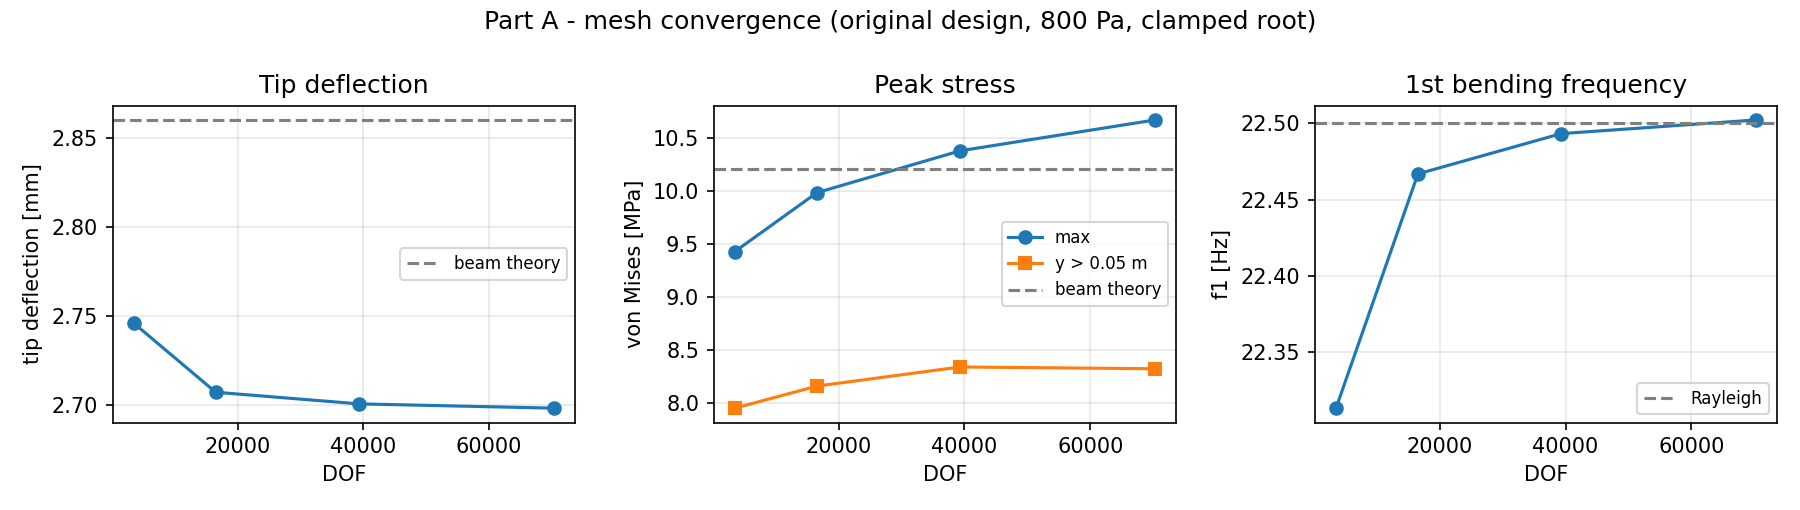
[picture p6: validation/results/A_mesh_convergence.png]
mesh convergence

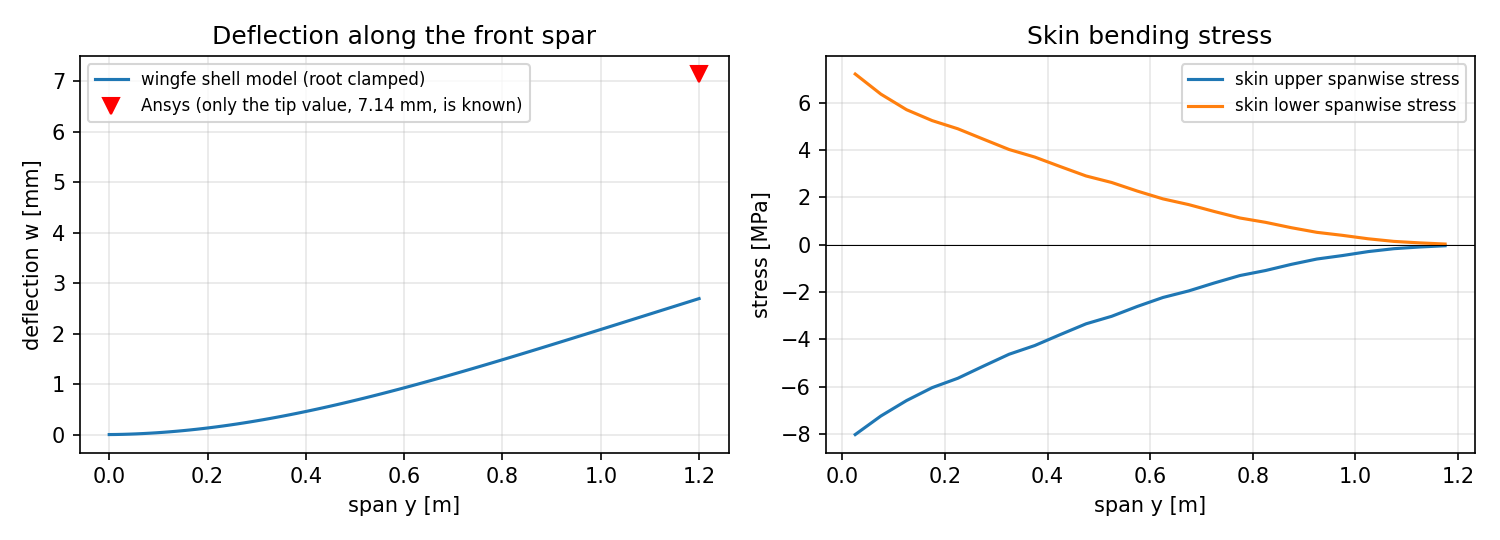
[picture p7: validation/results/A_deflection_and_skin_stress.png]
deflection and skin stress

mode shapes

### Part B: design load case

| Input | Value |
|---|---|
| MTOW (assumed in the project) | 5.0 kg, W = 49.05 N |
| Limit load factor / safety factor / ultimate | 4.0 / 1.5 / **6.0** |
| Wing | S = 0.54 m², AR = 10.67 |
| Lifting line | span efficiency e = 0.942, C_Lα = 5.16 /rad |
| Stall speed (C_Lmax 1.2) / manoeuvre speed | 11.1 m/s / 22.2 m/s |
| Semi-span lift, limit / ultimate | 98.1 N / **147.2 N** |

The lift distribution comes from lifting-line theory, with centre of pressure at
25 % chord. It is applied as a vertical load on the upper skin
([B_spanwise_lift_ultimate.csv](results/B_spanwise_lift_ultimate.csv)).
Inertia relief from the wing's own mass is ignored, which is conservative.

At ultimate load, **the original 8 mm design reaches 3.4 MPa and deflects
0.8 mm**: a reserve factor of 92 on ultimate strength, and 123 on yield at limit
load. It weighs 12.8 kg per semi-span, so both wings
together weigh 5.1 times the whole aircraft.

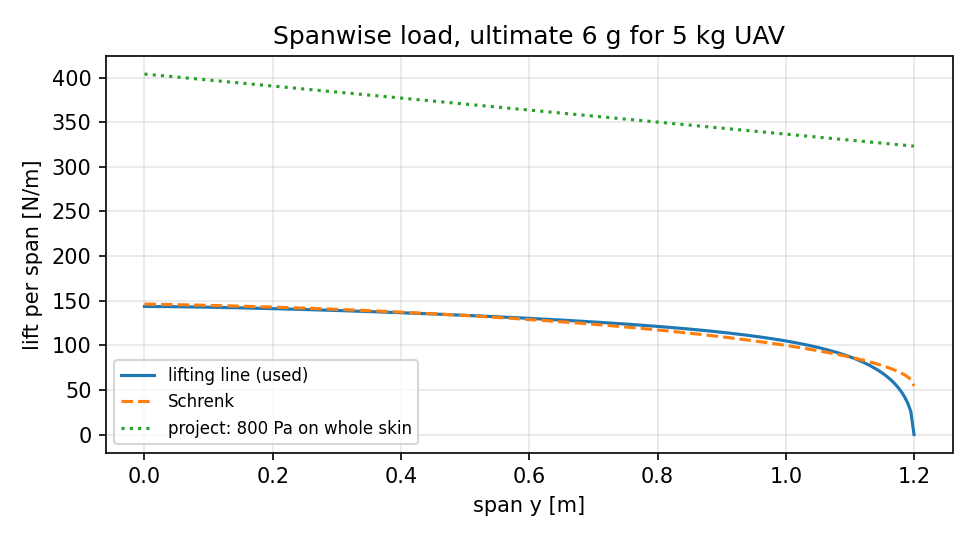
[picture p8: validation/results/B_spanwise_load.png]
spanwise load


### Part C: aluminium skin sizing ([C_aluminium_sizing.csv](results/C_aluminium_sizing.csv))

Al 6061-T6 (Sy 276 MPa, Su 310 MPa); webs 1.5 mm, ribs 1.0 mm. As is usual in
aircraft design, yield is checked at limit load (no permanent set), and ultimate
strength and linear buckling at ultimate load (no failure). Deflection is quoted
at limit load.

| Skin | Semi-span mass | Tip deflection @ limit | Max vM @ limit | RF yield @ limit | Max vM @ ultimate | RF ultimate | Buckling factor @ ultimate | f1 | Torsion | OK? |
|---|---|---|---|---|---|---|---|---|---|---|
| 0.4 mm | 0.93 kg | 10.0 mm | 32.8 MPa | 8.4 | 49.2 MPa | 6.3 | **0.91** | 19.4 Hz | 185 Hz | no (buckles) |
| **0.5 mm** | **1.08 kg** | 8.2 mm | 26.9 MPa | 10.2 | 40.4 MPa | 7.7 | **1.40** | 19.9 Hz | 190 Hz | **yes** |
| 0.6 mm | 1.22 kg | 7.0 mm | 23.1 MPa | 11.9 | 34.7 MPa | 8.9 | 2.03 | 20.2 Hz | 194 Hz | yes |
| 0.8 mm | 1.52 kg | 5.4 mm | 17.9 MPa | 15.4 | 26.9 MPa | 11.5 | 3.72 | 20.7 Hz | 199 Hz | yes |
| 1.0 mm | 1.82 kg | 4.4 mm | 14.6 MPa | 18.9 | 21.9 MPa | 14.1 | 6.05 | 21.0 Hz | 201 Hz | yes |
| 1.2 mm | 2.12 kg | 3.7 mm | 12.3 MPa | 22.4 | 18.5 MPa | 16.8 | 9.03 | 21.3 Hz | 203 Hz | yes |
| 1.5 mm | 2.56 kg | 3.0 mm | 9.9 MPa | 27.8 | 14.9 MPa | 20.8 | 14.8 | 21.5 Hz | 205 Hz | yes |

**Skin buckling, not strength, sizes the skin.** Even the 0.4 mm skin has a
reserve factor of 8.4 on yield at limit load and 6.3 on ultimate strength, but
it buckles below ultimate. The first
buckling mode is a local bulge of the upper skin in the root bay.

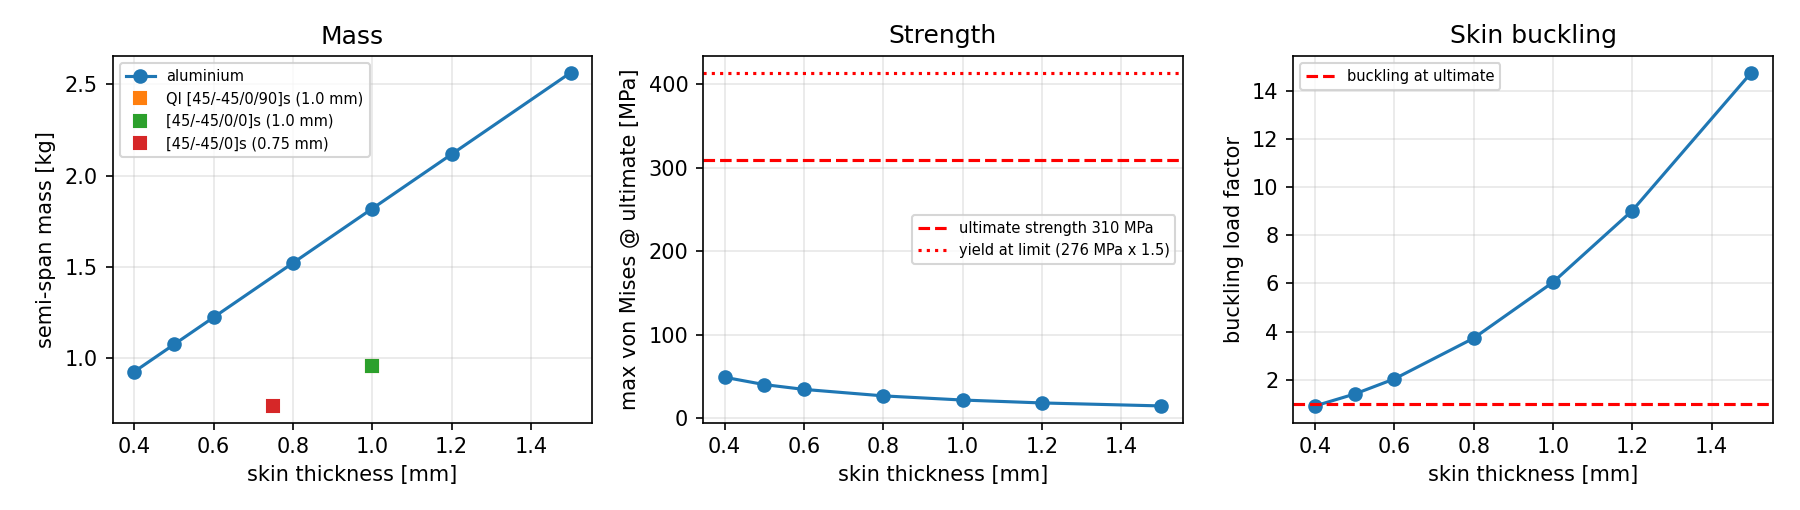
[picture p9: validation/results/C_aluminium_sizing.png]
sizing

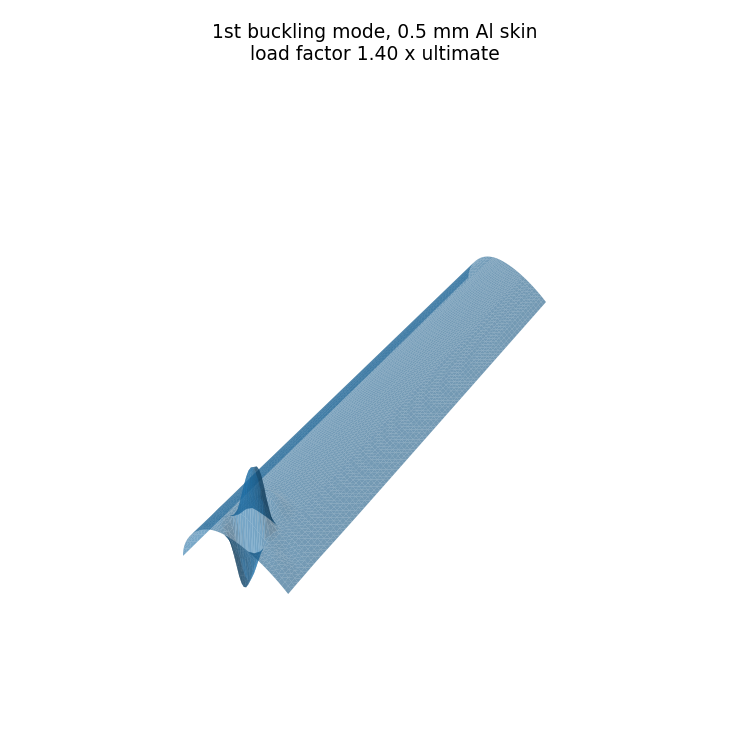
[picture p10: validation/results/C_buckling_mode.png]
buckling mode


### Part D: CFRP laminates ([D_cfrp_laminates.csv](results/D_cfrp_laminates.csv))

T300/5208 plies, 0.125 mm thick. Webs are [45/-45]s (0.5 mm) and ribs are
[0/90]s (0.5 mm), so part of the mass saving comes from lighter webs and ribs.
Ply angles are measured from the span direction. Failure is checked with
ply-level Tsai-Wu at ultimate load.

| Skin layup | Ex / Gxy | Semi-span mass | Tip @ limit | Tsai-Wu strength ratio | Buckling factor | f1 | Torsion |
|---|---|---|---|---|---|---|---|
| QI [45/-45/0/90]s, 1.0 mm | 69.7 / 26.9 GPa | 0.96 kg | 4.7 mm | 14.2 | 5.01 | 28.1 Hz | 270 Hz |
| [45/-45/0/0]s, 1.0 mm | 104.0 / 26.9 GPa | 0.96 kg | 3.1 mm | 19.7 | 4.11 | 34.4 Hz | 272 Hz |
| **[45/-45/0]s, 0.75 mm** | 77.7 / 33.5 GPa | **0.74 kg** | 5.4 mm | 12.5 | 2.05 | 29.7 Hz | 296 Hz |

Compared with the sized 0.5 mm aluminium wing, the 0.75 mm [45/-45/0]s wing is
**31 % lighter**, deflects **34 % less** and has a **50 % higher** first
frequency. This is the real composite advantage. The project's isotropic
"CFRP" (same E as aluminium) could not show it.

### Part E: fatigue, 0.5 mm aluminium design ([E_fatigue.csv](results/E_fatigue.csv))

Project S-N curve (10³…10⁷ cycles, 300…90 MPa), Goodman with Su = 310 MPa.

| Cycle | Stress used | Mean | Amplitude | Goodman equivalent | Life |
|---|---|---|---|---|---|
| 0 → 4 g manoeuvre | lower-skin spanwise tension | 12.2 MPa | 12.2 MPa | 12.7 MPa | > 10⁷ |
| 0 → 4 g manoeuvre | von Mises (project method) | 13.5 MPa | 13.5 MPa | 14.1 MPa | > 10⁷ |
| 1 g ± 0.5 g gust | lower-skin spanwise tension | 6.1 MPa | 3.0 MPa | 3.1 MPa | > 10⁷ |
| 1 g ± 1.0 g gust | lower-skin spanwise tension | 6.1 MPa | 6.1 MPa | 6.2 MPa | > 10⁷ |

All amplitudes sit far below the curve's endurance point (90 MPa at 10⁷ cycles).
They stay below it even with a stress-concentration factor of 3 at a fastener
hole. Fatigue of the skin is not critical; joints and fittings (not modelled)
are where fatigue design would focus.

### Part F: flutter and divergence estimate ([F_flutter.csv](results/F_flutter.csv))

Typical section at 75 % semi-span, with Theodorsen aerodynamics (V-g method).
Section properties come from the FE model: flexural axis at 46 % chord, centre
of gravity at 48–49 % chord. Frequencies are the FE first flap and first torsion
modes.

| Design | f_bend | f_torsion | μ | Flutter speed | Divergence speed | Flutter margin vs assumed 40 m/s dive |
|---|---|---|---|---|---|---|
| Original (8 mm Al) | 22.5 Hz | 214 Hz | 233 | 1204 m/s | 1392 m/s | 30 × |
| Sized Al (0.5 mm) | 19.9 Hz | 190 Hz | 19.4 | 313 m/s | 337 m/s | **7.8 ×** |
| CFRP QI (1.0 mm) | 28.0 Hz | 270 Hz | 17.3 | 427 m/s | 478 m/s | 10.7 × |

These speeds are far above any speed this UAV can fly, and above the range where
incompressible theory is valid. Read them as "no flutter or divergence concern",
not as exact values. The large torsion/bending frequency separation (about
9.6 : 1) of the two-spar box drives the margin. The CG sits slightly aft of the
flexural axis, so moving mass forward (for example a leading-edge spar)
would add margin.

### Limits of this re-analysis

* Shell idealisation: spars are single webs (no spar caps), no fasteners, no root
  fitting. Warping of the flat facets is below 5 × 10⁻⁶ m.
* Linear analysis; buckling is a linear eigenvalue estimate (no imperfections or
  post-buckling).
* The load uses lifting-line theory at the ultimate load factor, not CFD.
  Positive manoeuvre only.
* Material allowables are handbook values (Al 6061-T6; T300/5208 from Kaw).

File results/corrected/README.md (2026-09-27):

# Corrected Ansys results

Solved in Ansys Workbench 2026 R1 Student from `ansys/corrected/wing_fea_corrected.wbpj`,
a copy of the original project built by
[`validation/ansys_rerun/build_corrected_workbench.py`](../../validation/ansys_rerun/build_corrected_workbench.py).

Changes in every system:
* the 800 Pa pressure is suppressed;
* two APDL **Commands** objects are added: `root_clamp.inp` clamps the whole root
  section, and `design_load.inp` applies the design ultimate load (static systems
  only; 147.15 N per semi-span on the upper skin). Both are in
  [`validation/ansys_rerun/snippets/`](../../validation/ansys_rerun/snippets);
* weak springs are off;
* the modal systems find 12 modes.

| System | Result | Value |
|---|---|---|
| Aluminium static | max total deformation | **0.814 mm** |
| | max equivalent stress | **5.43 MPa** (local peak in rib 2; skin ≈ 3.4 MPa at the root) |
| | fatigue life (minimum) | 10⁷ cycles everywhere (end of the S-N curve: no fatigue damage) |
| "CFRP" static (isotropic, as in the project) | deformation / stress | 0.816 mm / 5.45 MPa |
| Aluminium modal | modes 1–12 | 22.77 flap 1 · 36.98 local · 64.05 local · 68.12 local · **123.23 flap 2** · **141.29 in-plane 1** · 157.74 local · 176.19 local · 211.11 local · **221.35 torsion 1** · 223.16 local · 266.20 local Hz |
| "CFRP" modal | modes 1–12 | every frequency is 1.2976 × the aluminium value (a density-only change) |

The local modes are vibrations of the 0.1 mm tip cap and of front-spar segments
between ribs. The spars are joined to the skin only by contact, not to the ribs.

Files:
* `*_total_deformation.png`, `*_equivalent_stress.png`, `al_static_fatigue_life.png`
* `*_modeNN_<f>Hz.png`
* `values_*.txt`: the values read from Mechanical

The modal "maximum deformation" values are mass-normalised and have no physical
size.

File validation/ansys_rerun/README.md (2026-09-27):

# Re-solving the saved decks in Ansys MAPDL

`rerun_in_mapdl.py` works as follows:

1. It takes the solver decks that Workbench wrote
   (`ansys/wing_fea_files/dp0/SYS-2|SYS-3/MECH/ds.dat`).
2. It writes modified copies into a temporary folder.
3. It runs **Ansys MAPDL 2026 R1 (Student)** in batch mode.
4. It reads back the results that the /POST1 commands appended to each copy
   write out.

The student's mesh, contacts and materials are used unchanged. Only the
corrections listed below are inserted just before `solve`; the original files
are never modified.

```bash
python validation/ansys_rerun/rerun_in_mapdl.py   # ~5-10 min; set AWP_ROOT261 if Ansys is elsewhere
```

| Case | Change to the saved deck |
|---|---|
| R0 / M0 | none (static / modal deck exactly as saved) |
| R1 / M1 | every node in the root plane (y = 0) clamped: skin edge, spar root faces and root cap; modal with 12 modes |
| R2 | as R1, and the 800 Pa pressure replaced by the design ultimate load: lifting-line lift for a 5 kg UAV at 6 g (147.15 N per semi-span), centre of pressure at 25 % chord, as nodal forces on the upper-skin nodes |

## Static ([static_results.csv](static_results.csv))

| Case | Max total deformation | Tip deflection | Max von Mises (where) | Skin max | Ribs max | Spars max | Load from reactions |
|---|---|---|---|---|---|---|---|
| R0 as saved | **7.143 mm** | 7.124 mm | **154.91 MPa** (rear-spar root, y = 0) | 52.5 MPa (y = 0.009 m) | 31.0 MPa (rib 1) | 154.9 MPa (y = 0) | 434.4 N |
| R1 root clamped | **2.698 mm** | 2.689 mm | 17.7 MPa (inside rib 2, local) | **10.60 MPa** (root) | 17.7 MPa (rib 2) | 7.4 MPa | 434.5 N |
| R2 root clamped, design load | **0.818 mm** | 0.812 mm | 5.5 MPa (rib 2) | **3.45 MPa** (root) | 5.5 MPa (rib 2) | 2.2 MPa | 147.1 N |

R0 reproduces the Workbench results exactly. Clamping the root is the only
change between R0 and R1, and it removes the 154.9 MPa artefact and 62 % of the
deflection.

| | Ansys, root clamped (R1/R2) | wingfe shell model | Beam theory |
|---|---|---|---|
| Tip deflection, 800 Pa | 2.698 mm | 2.698 mm | 2.86 mm |
| Skin root stress, 800 Pa | 10.6 MPa | 10.7 MPa | 10.2 MPa |
| Tip deflection, design load | 0.818 mm | 0.814 mm | – |
| Skin root stress, design load | 3.45 MPa | 3.36 MPa | – |

## Modal ([modal_results.csv](modal_results.csv))

**M0, as saved.** The six frequencies reproduce exactly (13.892 … 87.749 Hz).
The located peaks show what the local modes are:
- **Mode 3 (37.0 Hz):** at the tip leading edge.
- **Mode 5 (68.1 Hz):** at the tip trailing edge.
- **Mode 4 (63.9 Hz):** on the front spar between ribs 2 and 3 (x = 0.065 m,
  y = 0.31 m).

**M1, root clamped, 12 modes.**

| Mode type | Ansys, root clamped | wingfe shell model |
|---|---|---|
| Flapwise bending 1 | 22.77 Hz | 22.50 Hz |
| Flapwise bending 2 | 123.23 Hz | 123.42 Hz |
| In-plane bending 1 | 141.29 Hz | 141.37 Hz |
| Torsion 1 | 221.35 Hz | 213.96 Hz |
| Local modes | 36.98, 64.05, 68.12, 157.7, 176.2, 211.1, 223.2, 266.2 Hz | none below 700 Hz |

The local modes in the Ansys model sit at the 0.1 mm tip cap, or on the front
spar between ribs. The spars are joined to the skin only by bonded contact, and
not to the ribs, so short spar segments can vibrate on their own. The wingfe
model has shared nodes and a 2 mm tip rib, so these modes do not appear in it.

## Workbench check

`ansys/wing_fea.wbpj` (renamed from `complete.wbpj` together with its `_files`
folder) opens in Workbench 2026 R1 Student. This was checked in batch mode on a
copy. The systems listed were: "dummy", "static and fatigue aluminium",
"Modal aluminum", "CFRP static", "CFRP modal".

## Corrected Workbench project

`build_corrected_workbench.py` applies the same corrections inside a copy of
the Workbench project and re-solves it; see
[`results/corrected/`](../../results/corrected/README.md).

It does this with two mesh-independent APDL Commands snippets in
[`snippets/`](snippets): the root clamp, and the design load on the upper skin.
Workbench gives, for aluminium:
* 0.814 mm and 5.43 MPa under the design load (MAPDL re-run above: 0.818 mm and
  5.45 MPa);
* 22.77, 123.23, 141.29 and 221.35 Hz for the main modes, identical to M1.

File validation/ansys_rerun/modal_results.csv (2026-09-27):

case | mode | f_Hz | type | peak_x_m | peak_y_m | peak_z_m
M0_as_saved | 1 | 13.892 | flapwise bending | 0.200 | 1.200 | -0.000
M0_as_saved | 2 | 23.863 | in-plane (chordwise) bending | 0.000 | 1.200 | 0.001
M0_as_saved | 3 | 36.981 | local / panel | 0.000 | 1.200 | 0.001
M0_as_saved | 4 | 63.935 | local / panel | 0.065 | 0.310 | -0.006
M0_as_saved | 5 | 68.116 | local / panel | 0.200 | 1.200 | 0.000
M0_as_saved | 6 | 87.749 | flapwise bending | 0.200 | 1.200 | -0.000
M1_root_clamped | 1 | 22.769 | flapwise bending | 0.200 | 1.200 | -0.000
M1_root_clamped | 2 | 36.981 | local / panel | 0.000 | 1.200 | 0.001
M1_root_clamped | 3 | 64.053 | local / panel | 0.065 | 0.310 | -0.006
M1_root_clamped | 4 | 68.116 | local / panel | 0.200 | 1.200 | 0.000
M1_root_clamped | 5 | 123.226 | flapwise bending | 0.000 | 1.200 | 0.001
M1_root_clamped | 6 | 141.286 | in-plane (chordwise) bending | 0.000 | 1.200 | 0.001
M1_root_clamped | 7 | 157.738 | local / panel | 0.105 | 1.200 | 0.014
M1_root_clamped | 8 | 176.191 | local / panel | 0.067 | 0.440 | -0.006
M1_root_clamped | 9 | 211.108 | local / panel | 0.026 | 1.200 | 0.013
M1_root_clamped | 10 | 221.350 | torsion | 0.200 | 1.200 | -0.000
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

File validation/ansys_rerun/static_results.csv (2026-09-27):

case | max_total_deformation_mm | tip_w_mm | max_von_mises_MPa | y_of_max_m | max_von_mises_beyond_y0.05_MPa | applied_Fz_from_reactions_N | max_vm_MPa_skin | y_m_skin | max_vm_MPa_end_caps | y_m_end_caps | max_vm_MPa_ribs | y_m_ribs | max_vm_MPa_spars | y_m_spars
R0_as_saved | 7.143 | 7.124 | 154.91 | 0.000 | 31.04 | 434.43 | 52.53 | 0.009 | 0.69 | 1.200 | 31.04 | 0.110 | 154.91 | 0.000
R1_root_clamped | 2.698 | 2.689 | 17.69 | 0.219 | 17.69 | 434.54 | 10.60 | 0.000 | 0.26 | 1.200 | 17.69 | 0.219 | 7.44 | 0.100
R2_clamped_design_load | 0.818 | 0.812 | 5.45 | 0.219 | 5.45 | 147.13 | 3.45 | 0.000 | 0.08 | 1.200 | 5.45 | 0.219 | 2.19 | 0.100

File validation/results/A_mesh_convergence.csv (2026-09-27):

mesh_factor | dof | tip_w_mm | max_vm_MPa | max_vm_y>0.05_MPa | f1_Hz | f_inplane_Hz | f_torsion_Hz | mass_kg | time_s
0.5 | 3498 | 2.7458 | 9.427 | 7.955 | 22.313 | 141.25 | 212.60 | 12.810 | 2
1.0 | 16524 | 2.7069 | 9.981 | 8.162 | 22.467 | 141.34 | 213.82 | 12.838 | 12
1.5 | 39318 | 2.7004 | 10.375 | 8.342 | 22.493 | 141.36 | 213.94 | 12.844 | 38
2.0 | 70350 | 2.6980 | 10.666 | 8.325 | 22.502 | 141.37 | 213.96 | 12.846 | 93

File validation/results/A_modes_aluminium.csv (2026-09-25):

mode | f_Hz | type | X | Y | Z | RX | RY | RZ
1 | 22.50 | flapwise bending #1 | 0.000 | 0.000 | 0.584 | 0.404 | 0.004 | 0.000
2 | 123.42 | flapwise bending #2 | 0.000 | 0.000 | 0.199 | 0.164 | 0.013 | 0.000
3 | 141.37 | in-plane (chordwise) bending #1 | 0.584 | 0.000 | 0.000 | 0.000 | 0.000 | 0.401
4 | 213.96 | torsion #1 | 0.000 | 0.000 | 0.000 | 0.000 | 0.719 | 0.000
5 | 317.46 | flapwise bending #3 | 0.000 | 0.000 | 0.075 | 0.112 | 0.002 | 0.000
6 | 567.79 | torsion #2 | 0.001 | 0.000 | 0.010 | 0.019 | 0.086 | 0.001
7 | 574.89 | flapwise bending #4 | 0.001 | 0.000 | 0.029 | 0.053 | 0.024 | 0.001
8 | 700.65 | in-plane (chordwise) bending #2 | 0.208 | 0.000 | 0.000 | 0.000 | 0.002 | 0.177

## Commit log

2026-09-25 Organise UAV wing FEA project, audit the Ansys model and add verified re-analysis
    - cad/: final and archived Fusion 360 / STEP geometry, NACA 2412 coordinates
    - ansys/: final Workbench project (static, modal, fatigue, Al vs CFRP)
    - results/: original Ansys screenshots
    - docs/: model audit, literature review, development log, roadmap
    - tools/: solver-deck inspector, beam-theory check, Fusion airfoil import script
    - validation/: benchmark-verified shell FE code, corrected re-analysis
    (clamped root, lifting-line design load, sizing with buckling, CFRP
    laminates with Tsai-Wu, fatigue, flutter/divergence estimate)
    [A_mesh_convergence.csv, A_modes_aluminium.csv, B_spanwise_lift_ultimate.csv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]
2026-09-27 Fix issues found in review: code robustness, docs accuracy, strength checks
    Code
    - aero.py: fall back to np.trapz on NumPy < 2.0
    - run_flutter.py: section mass from the elements in the rib bay, so no node row
    on the bay edge is counted twice or missed; skip a design cleanly if it has no
    bending or torsion mode
    - run_validation.py: no crash when a mode type is missing; yield checked at limit
    load and ultimate strength at ultimate load; Ansys deflection plotted only at
    the tip, where it is known
    - inspect_ds_dat.py: find SURF154 pressure elements by type, not a fixed number
    - benchmarks.py: add lifting-line, Theodorsen-function, flutter-trend and
    whole-wing rigid-body checks (all ver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
    [A_mesh_convergence.csv, C_aluminium_sizing.csv, F_flutter.csv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]
2026-09-27 Add Ansys MAPDL re-run and corrected Workbench project
    - validation/ansys_rerun/rerun_in_mapdl.py: re-solves the saved decks in Ansys
    MAPDL as saved (reproduces 7.143 mm / 154.91 MPa exactly), with the root
    clamped (2.698 mm; 22.77 Hz bending, 221.35 Hz torsion) and with the design
    load (0.818 mm)
    - validation/ansys_rerun/build_corrected_workbench.py and snippets/: builds a
    corrected copy of the Workbench project (root clamp and design load as
    mesh-independent APDL commands, pressure suppressed, weak springs off,
    12 modes) and re-solves it, retrying on 2 cores if MAPDL lacks memory
    - ansys/corrected/: the corrected, solved Workbench project
    - results/corrected/: 29 result images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
    [modal_results.csv, static_results.csv]
2026-10-17 Separate original and corrected results; remove unused files
    - results/aluminium, results/cfrp -> results/original/ with a README that
    marks them as coming from the flawed set-up
    - README: corrected Ansys image at the top, a "Corrected Ansys results"
    table, original results section labelled as kept for reference, updated
    repository layout
    - remove unused CAD intermediates (cad/archive v2 and the reverted v5 variant)
    - small accuracy fixes: CG range 47.6-49.0 % chord (flutter section),
    bending-frequency agreement 1.2 %
